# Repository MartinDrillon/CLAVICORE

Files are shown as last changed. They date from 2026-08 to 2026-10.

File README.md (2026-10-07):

# Clavicore 
## Le projet
> Piloter un clavecin à distance grâce à un clavier ergonomique

## L’instrument
La base est une copie d’une épinette italienne de 1601, vendue dans les années 70 en kit par Heugel et montée par un amateur. L’instrument a été révisé (changement des cordes, réharmonisation à la plume, rebouchage d’une fente sur la table d’harmonie). 

Le système électronique sera intégré au corps de l’instrument.

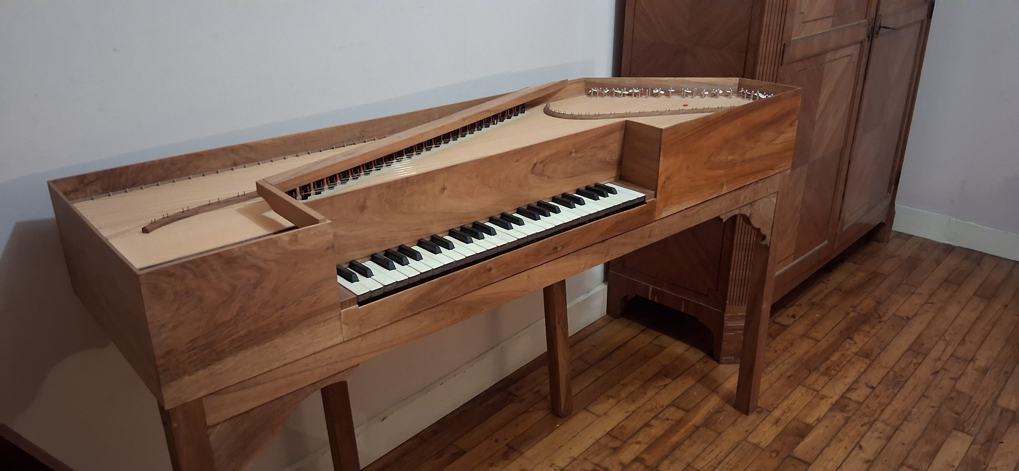
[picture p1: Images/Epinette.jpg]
Épinette


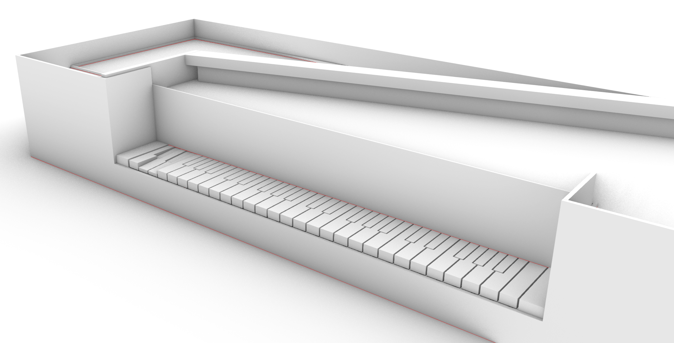
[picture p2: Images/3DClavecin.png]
3D Clavecin


## L’automatisation

## Moitié « Moteur »
*PCB en cours de fabrication*

La carte de contrôle est basée sur un RP2354B avec un DRV8874 par solénoïde pour un contrôle bidirectionnel. Cinq cartes permettent de gérer les 49 touches du clavier. Les cartes communiquent en CAN.

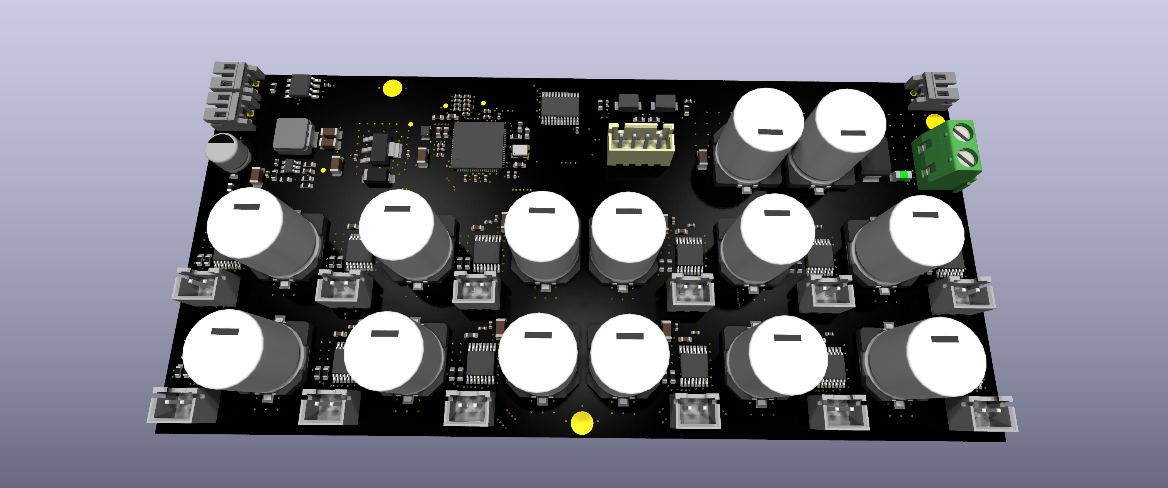
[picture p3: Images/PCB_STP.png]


### Moitié « Clavier »
*PCB en cours de fabrication*

Simple matrice de touches gérée par un Pico 2. Les événements « touches pressées » sont communiqués en CAN avec la partie « moteur » du système. Ils pourront également être transmis en MIDI à un ordinateur.

Ce projet utilisera une base de clavier ergonomique (https://github.com/MartinDrillon/IteMX3-) adaptée pour recevoir une disposition de type « Wiki-Haydn ». Une présentation plus détaillée du clavier est à venir. 

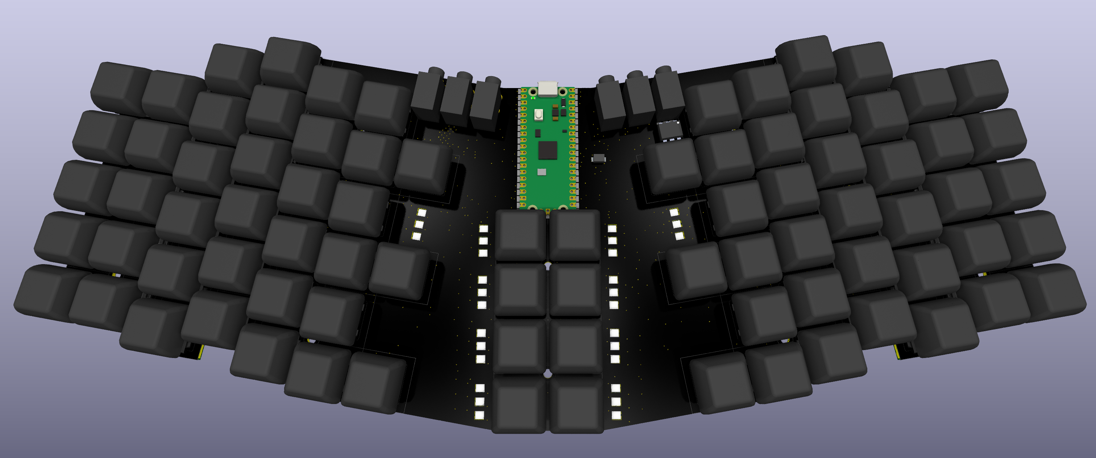
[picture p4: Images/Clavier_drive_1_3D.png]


## Les solénoïdes
Les solénoïdes sont les éléments centraux du montage. Ils doivent être réalisés sur mesure. Ceux disponibles sur le marché sont :
- Trop bruyants
- Trop encombrants
- Trop puissants ou trop faibles
- Trop chers (~5 € pièce pour la référence la plus adaptée)

### Le cahier des charges
- Bobine de 28 mm x 15 mm Ø max, intégrée au corps du clavecin, pour être invisible et conserver la possibilité de jouer normalement.   
- Noyau constitué d’un aimant néodyme de 13 mm x 6 mm Ø N48 fixé sous la touche.
- Alimentation en 24 volts, courant de 2 à 3 ampères
    - Au-delà, la chauffe de la bobine et la puissance nécessaire à un accord deviennent trop importantes
    - En deçà, la force n’est pas suffisante ou le nombre de spires devient trop élevé
- Fil d’un diamètre de 0,3 à 0,4 mm. 
    - Au-delà, la quantité de cuivre par bobine devient trop importante (coût, encombrement, bobinage complexe).
    - En deçà, la force est trop faible ou la chauffe est trop élevée. 

### Le prototype

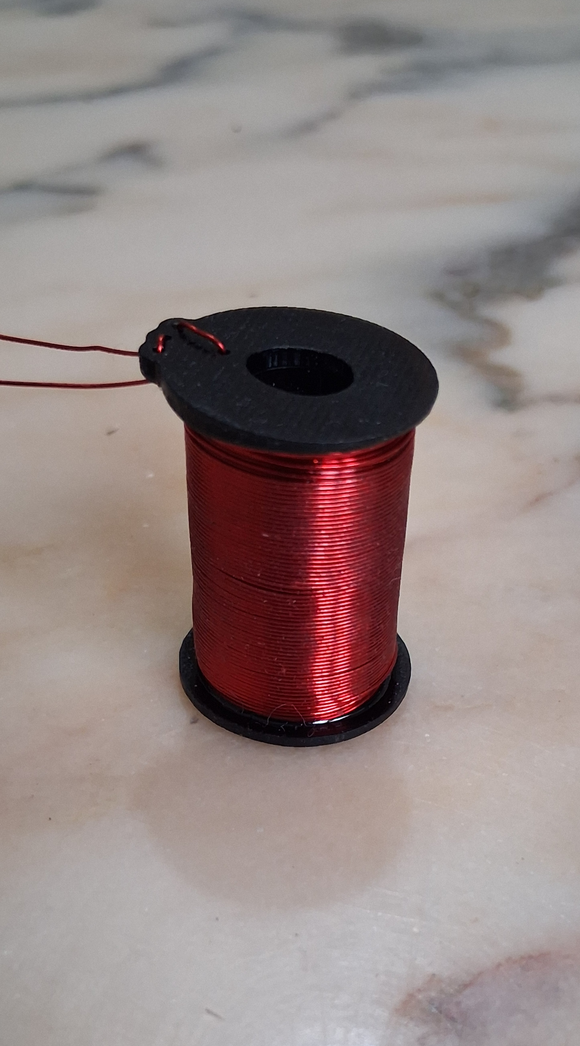
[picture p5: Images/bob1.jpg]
bobine de côté

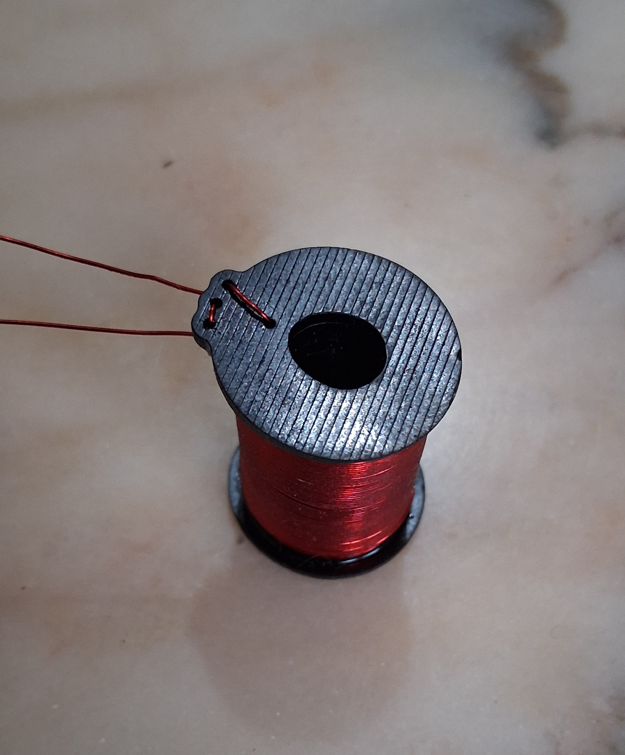
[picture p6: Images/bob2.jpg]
bobine plan


Le mandrin est imprimé en 3D avec une résine industrielle résistante à de hautes températures. Sa section est ovoïde pour permettre le mouvement de l’aimant (qui n’est pas parfaitement vertical, la touche s’enfonçant avec un angle) tout en minimisant l’écart avec les spires. La paroi intérieure ne fait que 0,8mm d’épaisseur. Ce prototype tire environ 2,9 ampères pour 14 couches et un fil de 0,35mm. 

La force max estimée est de 3N, soit environ le double de ce qui est nécessaire au pincement d’une corde. Cette marge devra permettre de garantir la réactivité du système et de compenser la perte de puissance causée par l’échauffement. La force exacte appliquée sera de toute façon controllé en PWM (par exemple 100% pour le pincement, puis très limité pour le maintien de la corde). Ces éléments devront être validés avec un premier prototype fonctionnel.

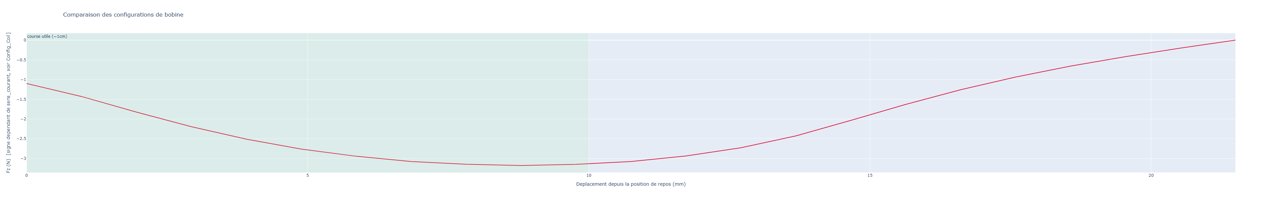
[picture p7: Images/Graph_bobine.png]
Évaluation de la force


## L’état d’avancement 
- [X] Génération d’un script Magpylib pour réaliser un premier dimensionnement des solénoïdes 
- [X] Modélisation 3D de l’instrument
- [X] Conception et impression 3D du corps de la bobine intégré sous les touches
- [X] Premier test concluant avec un fil de 0,4 mm - 2 ampères - 24 volts
- [X] Conception des cartes de pilotage pour l’ensemble du clavecin *pcb en cours de fabrication*
- [X] Conception du clavier ergonomique *pcb en cours de fabrication*
- [ ] Programmation de l’ensemble *en cours*
- [ ] Réalisation artisanale de 50 bobines homogènes et installation du système ! 

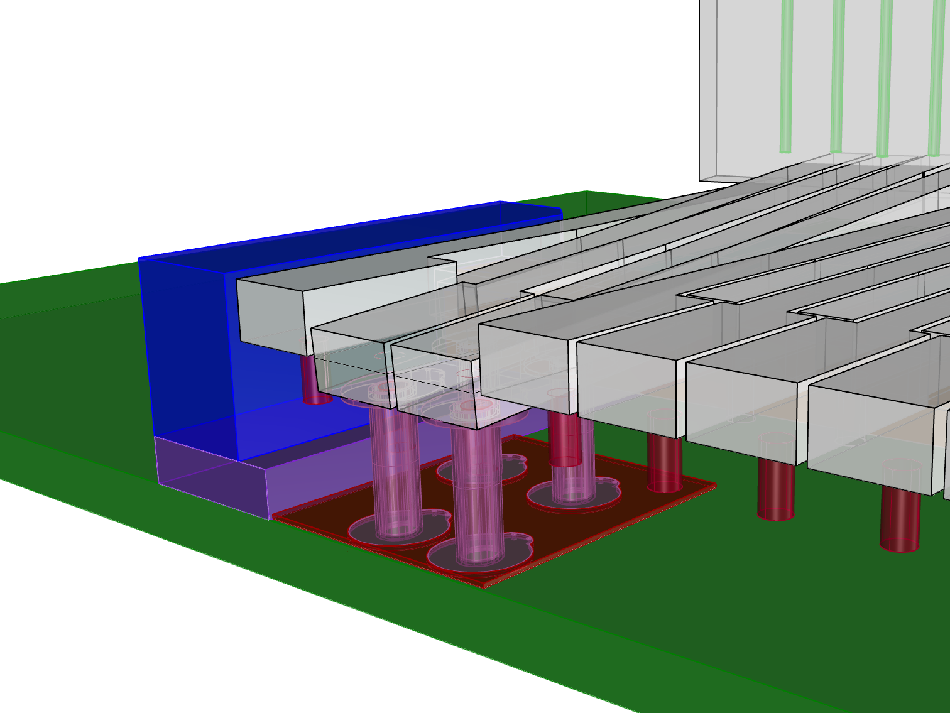
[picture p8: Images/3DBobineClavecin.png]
3D Bobine Clavecin


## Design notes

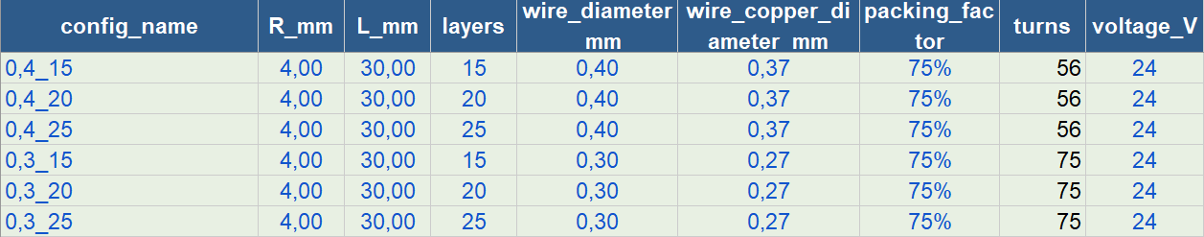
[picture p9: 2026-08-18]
Images/CaracteristiqueBobine.png

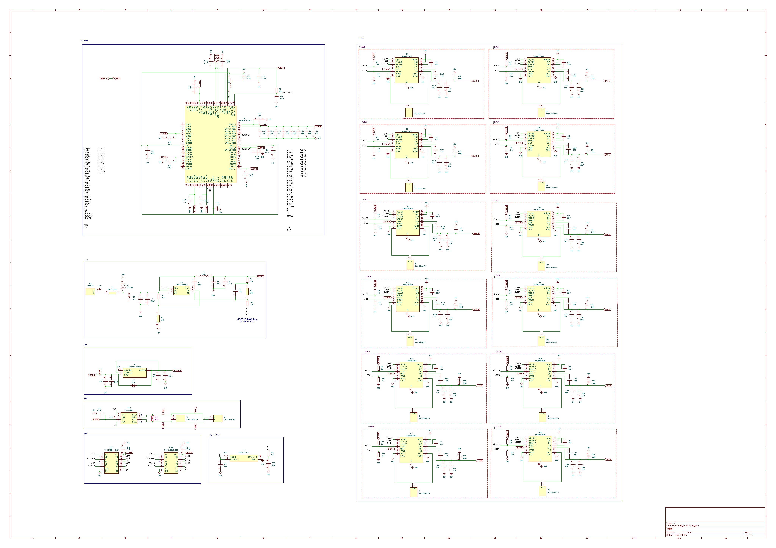
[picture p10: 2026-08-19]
Images/Schéma_moteur.jpg

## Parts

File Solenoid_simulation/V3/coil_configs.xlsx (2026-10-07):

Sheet: Config_Coil
Configurations de bobines — comparaison / dimensionnement
Une ligne = une configuration de bobine. L'aimant N'EST PLUS fixe dans le code : chaque ligne pointe vers une definition d'aimant reutilisable via 'magnet_config' (voir l'onglet Config_Magnet — 'S-06-13-N48' fourni en exemple). turns (couche 0) CALCULE = INT(L_mm/wire_diameter_mm*packing_factor) (texte noir = ne pas modifier). Bobinage IMBRIQUE (orthocyclique) : -1 tour/couche, rayon +diametre*racine(3)/2 par couche. Pour ajouter des tours, joue sur 'layers'. wire_diameter_mm = diametre TOTAL du fil (cuivre + email). wire_copper_diameter_mm = diametre du CUIVRE NU, CALCULE AUTOMATIQUEMENT (texte noir) = wire_diameter_mm - 0.03mm (epaisseur d'email typique) — tape une valeur directement dans la cellule pour ecraser ce calcul si tu as mesure ton fil au pied a coulisse, ou si resistance_measured_ohm (onglet Mesures) indique un diametre effectif different. sens_courant = 'Attire' ou 'Repousse' (liste deroulante) : inverse le sens du courant dans la bobine, donc le sens de la force sur l'aimant (l'orientation de l'aimant lui-meme, definie dans Config_Magnet, reste inchangee). voltage_V = tension d'alim, le courant en resulte (loi d'Ohm). empty_bobbin_weight_g = poids support vide (guide de pesee). quantity = nombre de bobines identiques (cuivre total).
config_name | R_mm | L_mm | layers | wire_diameter_mm | wire_copper_diameter_mm | packing_factor | turns | voltage_V | sens_courant | magnet_config | empty_bobbin_weight_g | quantity
0,35_14 | 4.00 | 28.00 | 14 | 0.35 |  | 90% |  | 24 | Attire | S-06-13-N48 | 1.70 | 50
 |  |  |  |  |  | 80%

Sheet: Config_Magnet
Configurations d'aimants — reutilisables, referencees depuis Config_Coil
Une ligne = un aimant reutilisable, reference depuis Config_Coil via 'magnet_config' (plusieurs bobines peuvent partager le meme aimant). shape = 'cylindre' ou 'carre' (liste deroulante) ; pour 'cylindre', dim1_mm = diametre et dim2_mm est ignore ; pour 'carre' (rectangulaire), dim1_mm et dim2_mm sont les deux cotes de la section. height_mm = epaisseur selon l'axe d'aimantation (les deux formes). grade = grade neodyme standard (liste deroulante, table de reference a droite) -> Br_T = milieu de plage du grade choisi, calcule automatiquement (texte noir). Renseigne Br_override_T (bleu) si tu as la valeur Br exacte de la fiche technique : elle remplace alors le calcul automatique. Position de depart (x0_mm, y0_mm, z0_mm) = position du CENTRE de l'aimant, en mm, avec le CENTRE DE LA BOBINE a l'origine (0,0,0). La bobine (longueur L_mm, onglet Config_Coil) s'etend de -L/2 a +L/2 selon Z. Exemple : aimant pose a fleur du sommet de la bobine (gap=0) -> z0_mm = L/2 + height_mm/2. x0/y0 permettent de simuler un aimant decale lateralement (hors axe).
 |  |  |  |  |  |  |  |  |  |  | Table de reference (grades neodyme standard)
magnet_config | shape | grade | Br_override_T | Br_T | dim1_mm | dim2_mm | height_mm | x0_mm | y0_mm | z0_mm | Grade | Br_min_T | Br_max_T | Br_mid_T
S-06-13-N48 | cylindre | N48 |  |  | 6.00 |  | 13.00 | 0.00 | 0.00 | 21.50 | N35 | 1.170 | 1.220
 |  |  |  |  |  |  |  |  |  |  | N38 | 1.220 | 1.250
 |  |  |  |  |  |  |  |  |  |  | N40 | 1.250 | 1.280
 |  |  |  |  |  |  |  |  |  |  | N42 | 1.280 | 1.320
 |  |  |  |  |  |  |  |  |  |  | N45 | 1.320 | 1.380
 |  |  |  |  |  |  |  |  |  |  | N48 | 1.380 | 1.420
 |  |  |  |  |  |  |  |  |  |  | N50 | 1.400 | 1.450
 |  |  |  |  |  |  |  |  |  |  | N52 | 1.430 | 1.480
 |  |  |  |  |  |  |  |  |  |  | N55 | 1.470 | 1.530
 |  |  |  |  |  |  |  |  |  |  | Source : magmamagnets.com — tableau des caracteristiques
 |  |  |  |  |  |  |  |  |  |  | magnetiques (grades N35-N55). Br_mid_T = milieu de plage.

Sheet: Bobinage_Fabrication
Bobinage — poids, longueur de fil et guide de fabrication
Densite Cu (g/cm3): | 8.92 | Cuivre étamé
Guide de realisation : dimensions, longueur de fil a couper et poids de cuivre pour chaque configuration (depuis Config_Coil). turns_total = somme des tours sur toutes les couches imbriquees. wire_length_m = longueur totale de fil a bobiner. copper_weight_target_g = poids de cuivre pour UNE bobine ; copper_weight_total_qty_g = pour 'quantity' bobines identiques. total_weight_target_g = poids d'une bobine finie (cuivre + support vide) ; total_weight_all_coils_g = poids total du lot complet. lateral_surface_m2 = surface laterale du bobinage (utilisee par l'onglet Electrique pour estimer la convection thermique).
config_name | turns_total | wire_length_m | wire_section_mm2 | outer_diameter_mm | copper_weight_target_g | copper_weight_total_qty_g | total_weight_target_g | lateral_surface_m2 | empty_bobbin_weight_g | quantity | total_weight_all_coils_g

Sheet: Electrique
Caracteristiques electriques et de chauffe (depuis Config_Coil / Bobinage_Fabrication)
Resistivite Cu (Ohm.m): | 1.68e-08 | Temp. ambiante (C): | 25 | h convection (W/m2K): | 10 | Temp. max aimant (C): | 80 | Densite max continue (A/mm2): | 4.0 | Position de maintien (mm): | 10.0 | Duty cycle PWM cible (%): | 3.0% | Constante estim. (N/A.tour): | 0.001073
IMPULSION (orange) = pleine tension sans PWM, bref -> echauffement volontairement extreme, normal. MAINTIEN (vert) = PWM continu -> c'est LUI qui doit rester 'OK'. duty_cycle_hold (bleu) = pourcentage de temps ON du PWM que TU choisis ; par defaut il reprend 'Duty cycle PWM cible' ci-dessus mais peut etre modifie ligne par ligne. force_hold_N / force_hold_g = force de maintien RESULTANTE a ce duty cycle (calculee, ce n'est plus une cible qu'on vise). force_estimate_rapide_N = estimation rapide (F proportionnel aux ampere-tours, PAS ampere-tours^2 : l'aimant est un dipole permanent, pas un noyau qui sature) calibree sur la geometrie ET l'aimant par defaut (R=4mm/L=30mm, S-06-13-N48) -- fiable pres de cette config, ecart possible si la bobine OU l'aimant s'eloigne beaucoup de cette reference. force_dispo_maintien_N (violet) = vraie valeur simulee (magpylib), injectee par batch_compare.py. force_utilisee_N prend la valeur simulee si disponible sinon l'estimation rapide (source_force l'indique).
 | IMPULSION (plein voltage, bref) |  |  |  |  |  | MAINTIEN (PWM, soutenu)
config_name | resistance_ohm | voltage_V | current_full_A | current_density_full_A_mm2 | power_full_W | delta_T_full_C | force_estimate_rapide_N | force_dispo_maintien_N | force_utilisee_N | source_force | duty_cycle_hold | force_hold_N | force_hold_g | current_hold_A | current_density_hold_A_mm2 | power_hold_W | delta_T_hold_C | coil_temp_hold_C | margin_hold_C | status_hold
 |  |  |  |  |  |  |  | 3.1331
 |  |  |  |  |  |  |  | 3.6382
 |  |  |  |  |  |  |  | 3.2336 |  |  | 3.0%
 |  |  |  |  |  |  |  | 2.4188
 |  |  |  |  |  |  |  | 2.1750
 |  |  |  |  |  |  |  | 1.9710

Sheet: Mesures
Mesures — calibration a partir de la resistance mesuree
Mesures reelles faites au multimetre APRES bobinage (optionnel). resistance_measured_ohm (bleu) = ta mesure reelle. Si elle est renseignee, copper_diameter_effective_mm est recalcule a partir de cette resistance (diametre de cuivre qui, avec la longueur de fil theorique, donnerait exactement cette resistance). Compare-le a copper_diameter_theorique_mm (repris de Config_Coil) : si l'ecart est significatif, reporte copper_diameter_effective_mm dans Config_Coil!wire_copper_diameter_mm (en ecrasant la formule automatique) pour recaler tout le modele (Bobinage_Fabrication, Electrique) sur ta fabrication reelle.
config_name | resistance_theorique_ohm | resistance_measured_ohm | ecart_resistance_pct | copper_diameter_theorique_mm | copper_diameter_effective_mm | ecart_diametre_mm

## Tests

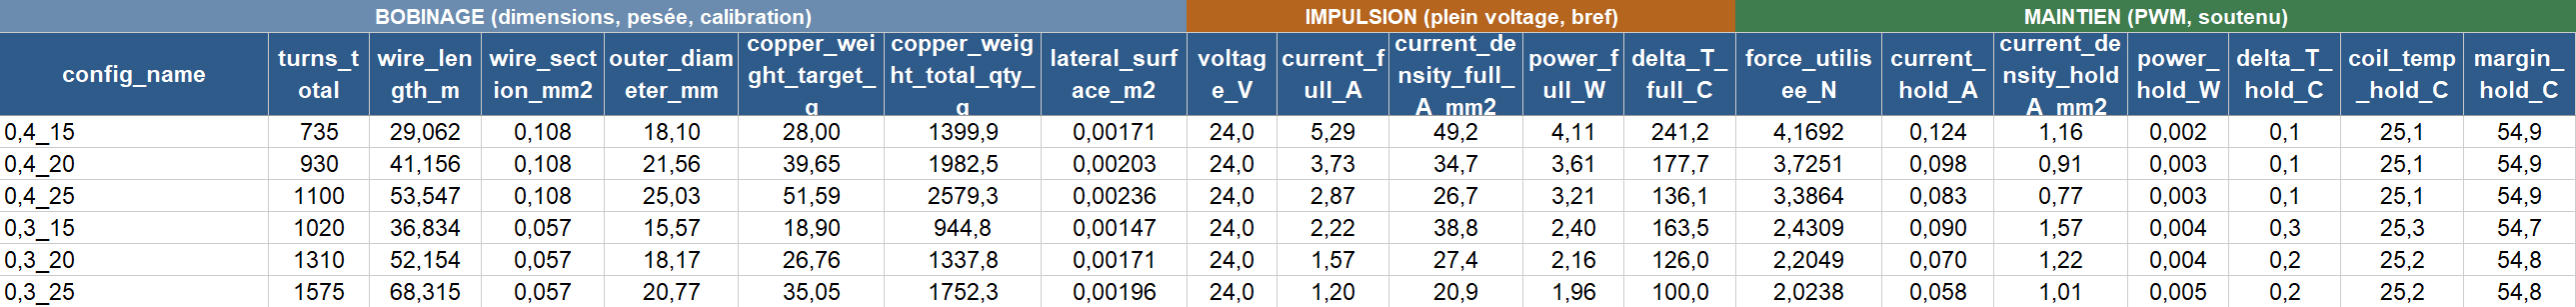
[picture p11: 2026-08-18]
Images/Resultat_test.png

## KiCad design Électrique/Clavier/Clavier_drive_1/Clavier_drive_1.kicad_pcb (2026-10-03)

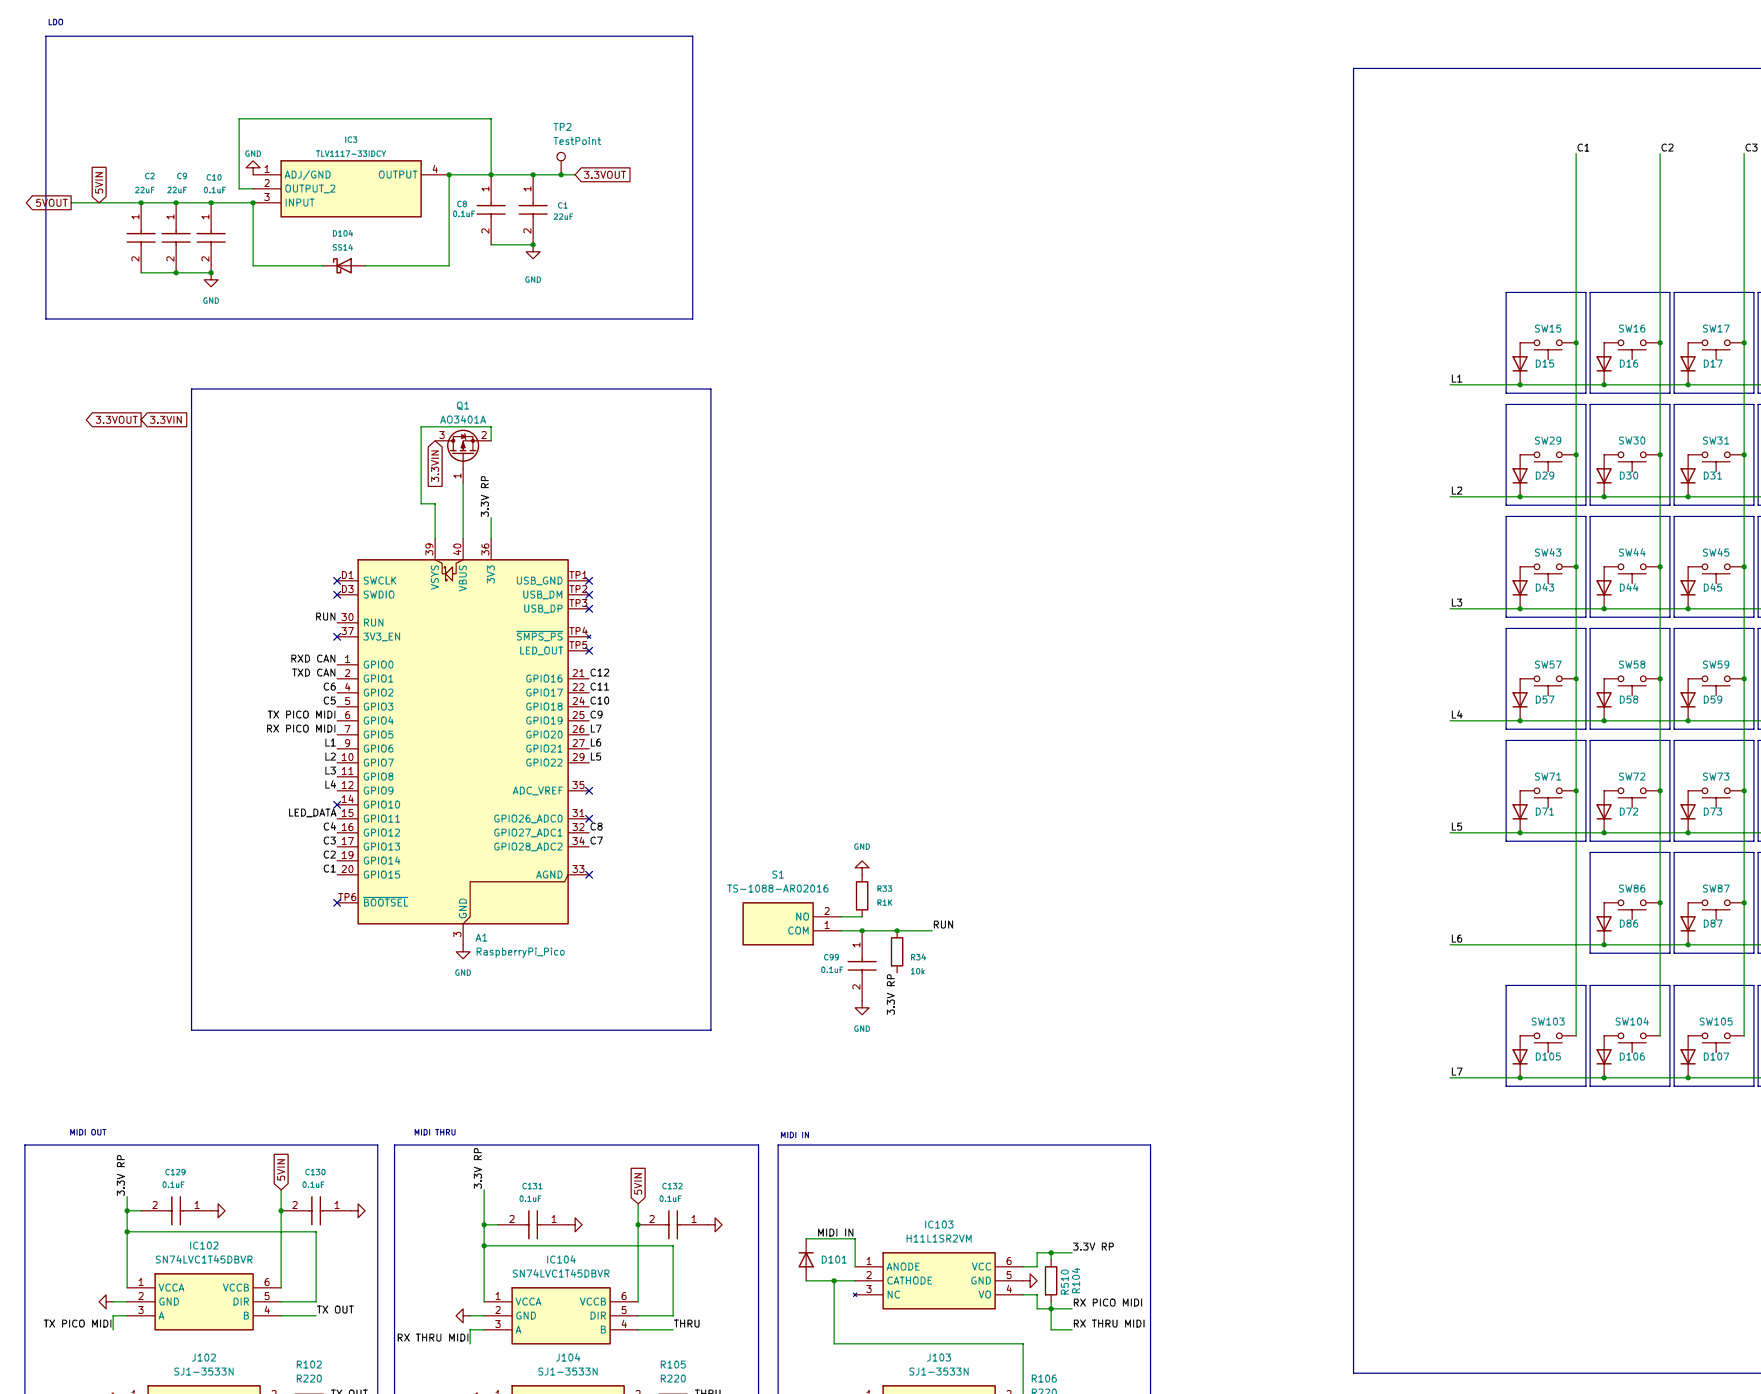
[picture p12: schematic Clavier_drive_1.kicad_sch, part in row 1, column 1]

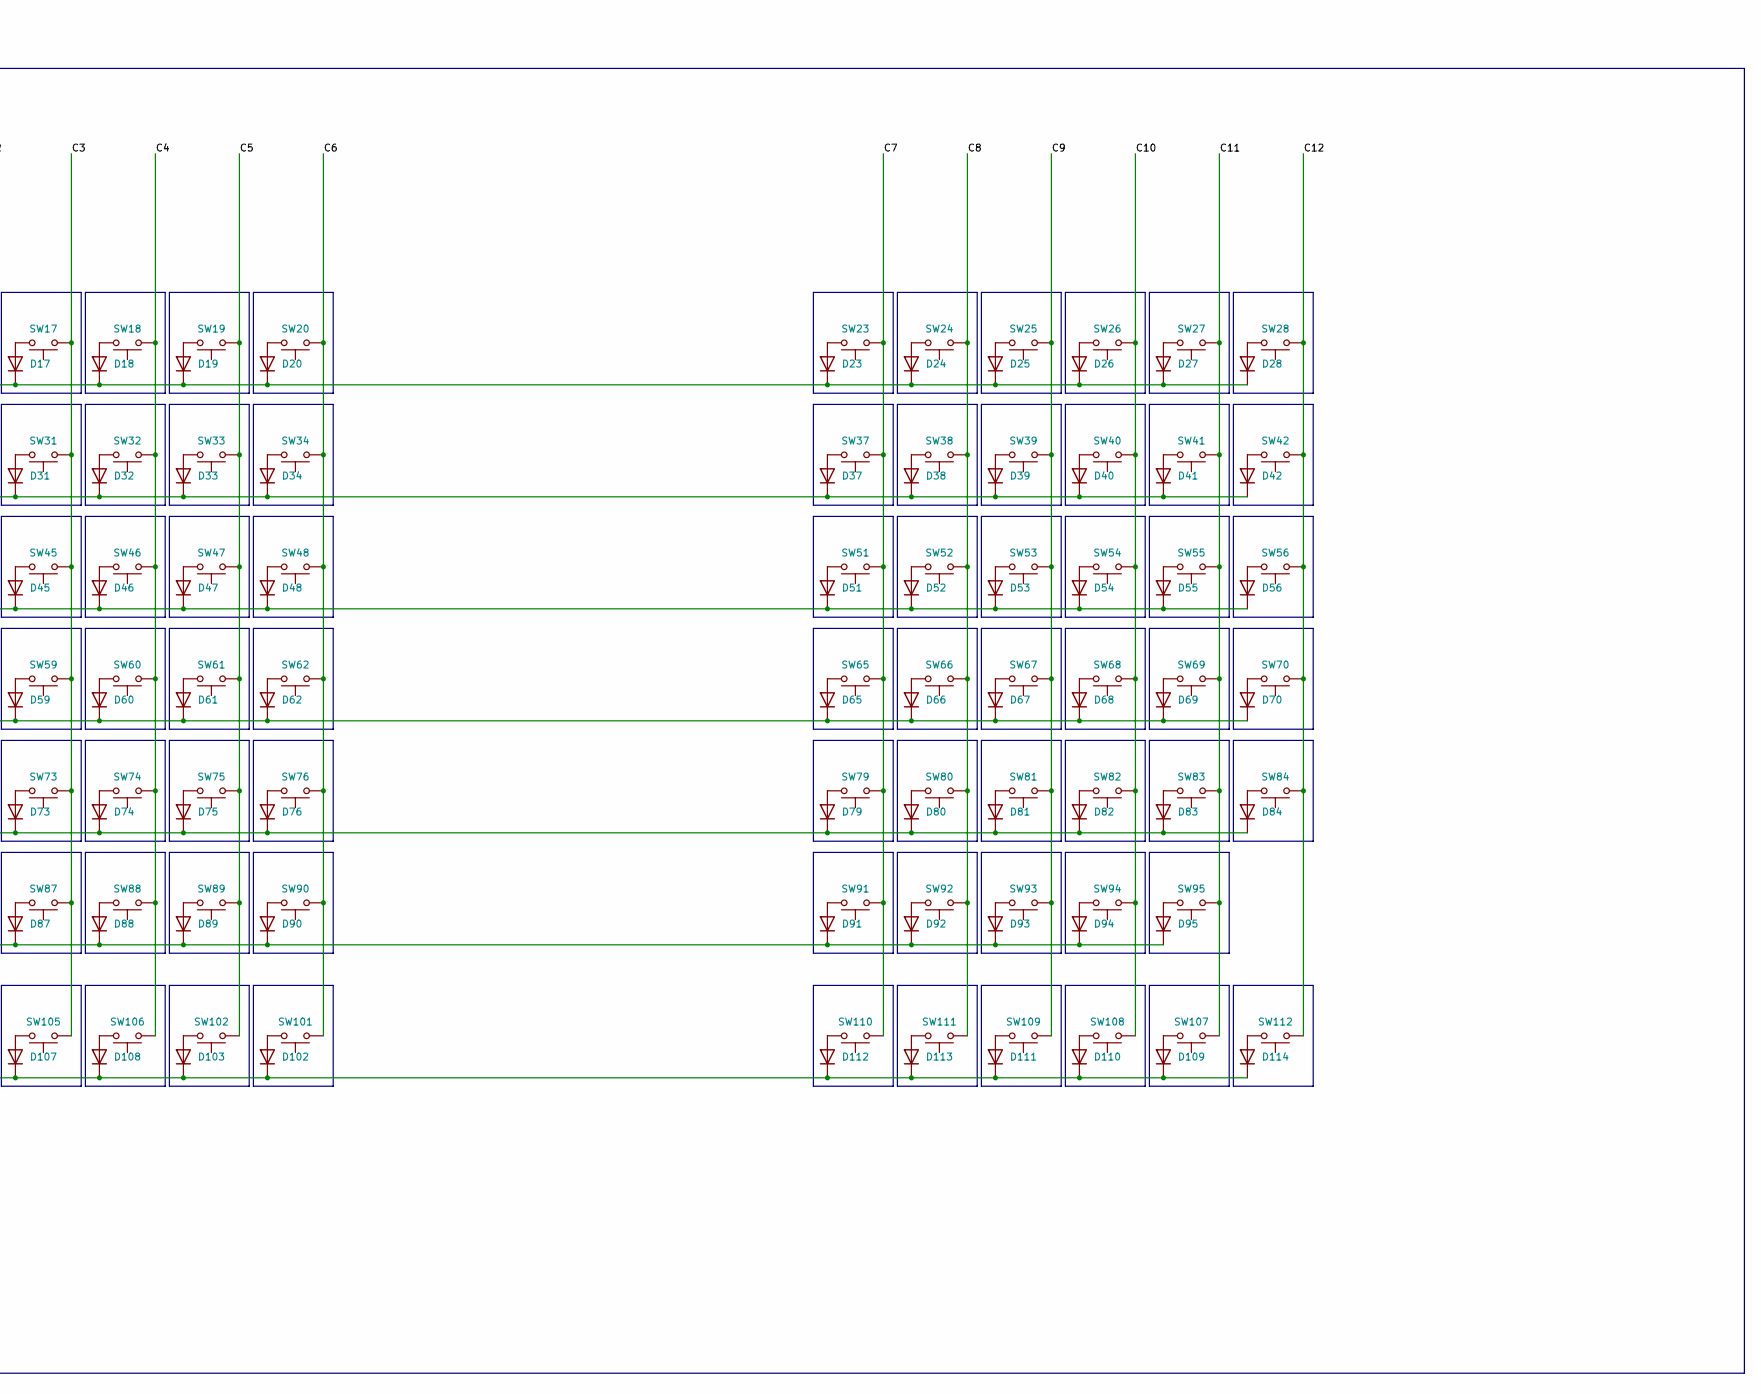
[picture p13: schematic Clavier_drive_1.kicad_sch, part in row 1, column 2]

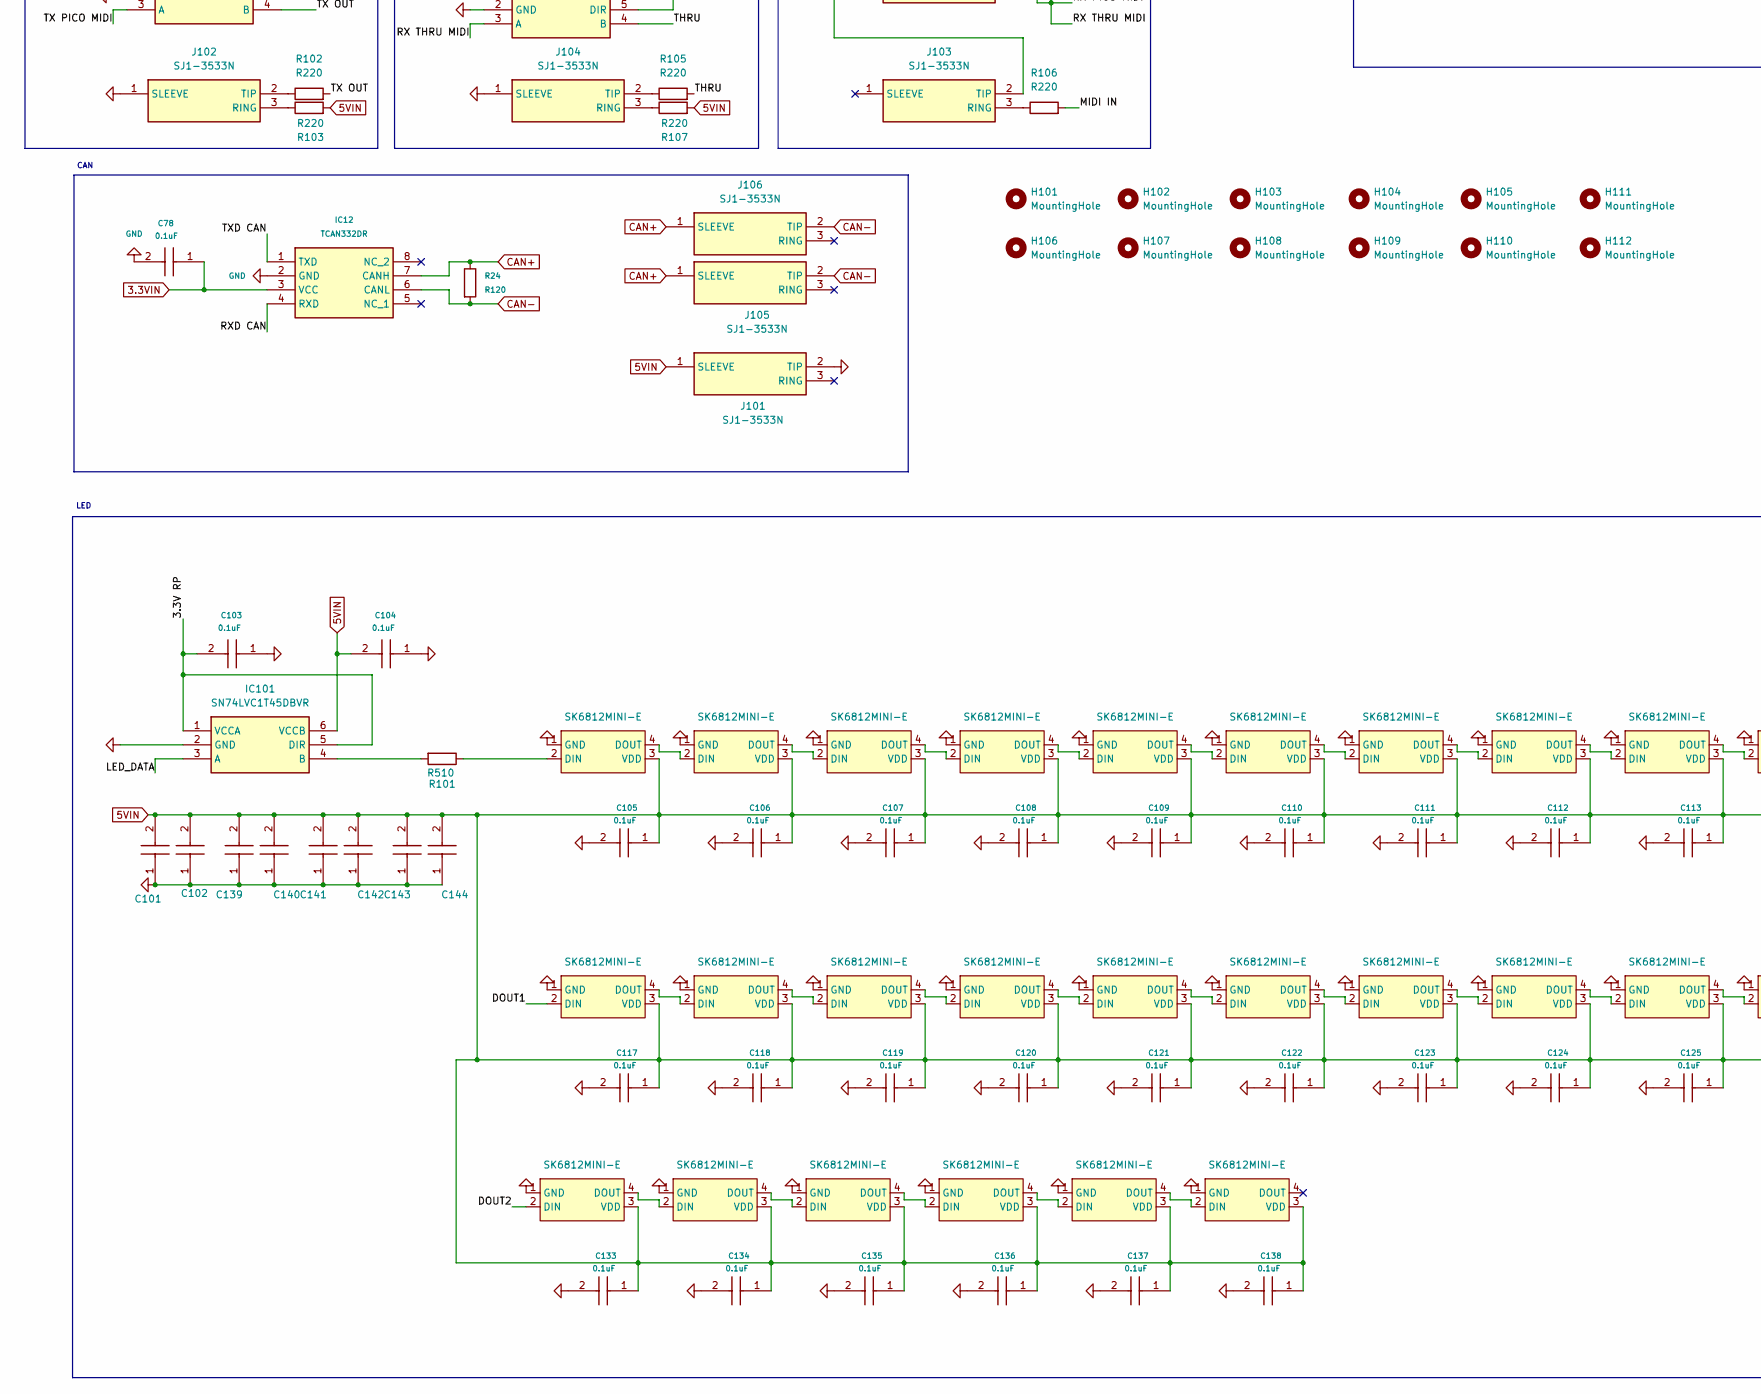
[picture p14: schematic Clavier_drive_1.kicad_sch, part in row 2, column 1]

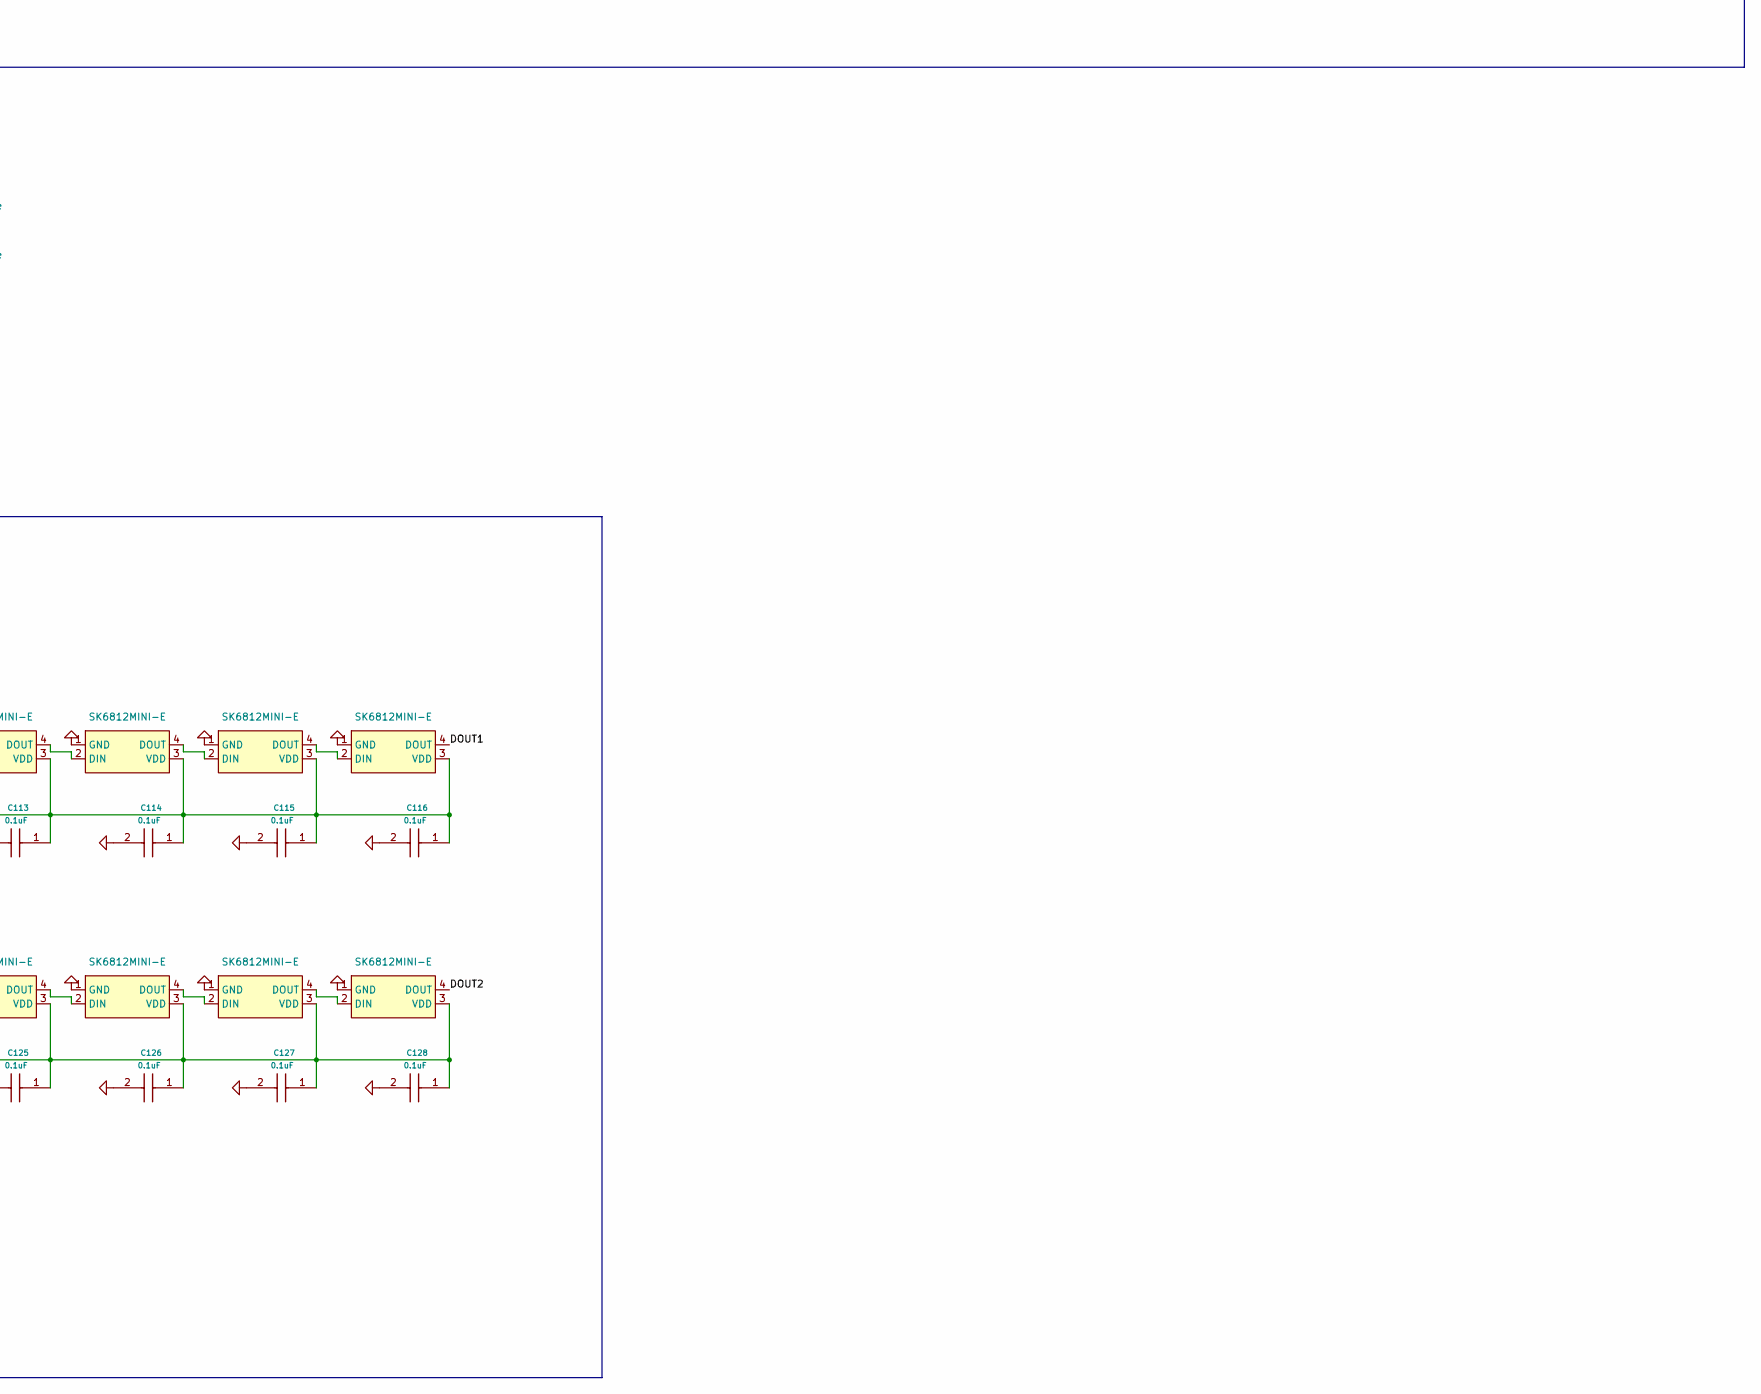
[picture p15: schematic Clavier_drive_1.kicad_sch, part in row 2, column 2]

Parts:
A1: RaspberryPi_Pico; RaspberryPi_Pico_SMD
C1, C2, C9: 22uF; C_1206_3216Metric; Mouser Part Number 187-CL31A226KAHNNNE
C8, C10, C78, C99, C103, C104, C105, C106, C107, C108, C109, C110, C111, C112, C113, C114, C115, C116, C117, C118, C119, C120, C121, C122, C123, C124, C125, C126, C127, C128, C129, C130, C131, C132, C133, C134, C135, C136, C137, C138: 0.1uF; C_0402_1005Metric; Mouser Part Number 603-CC603KRX7R9BB104
C101, C102, C139, C140, C141, C142, C143, C144: CL31A476MPHNNNE; CAPC3216X180N; Mouser Part Number 187-CL31A476MPHNNNE
D15, D16, D17, D18, D19, D20, D23, D24, D25, D26, D27, D28, D29, D30, D31, D32, D33, D34, D37, D38, D39, D40, D41, D42, D43, D44, D45, D46, D47, D48, D51, D52, D53, D54, D55, D56, D57, D58, D59, D60, D61, D62, D65, D66, D67, D68, D69, D70, D71, D72, D73, D74, D75, D76, D79, D80, D81, D82, D83, D84, D86, D87, D88, D89, D90, D91, D92, D93, D94, D95, D101, D102, D103, D105, D106, D107, D108, D109, D110, D111, D112, D113, D114: 1N4148W; D_SOD-123
D104: SS14; D_SMA
H101, H102, H103, H104, H105, H106, H107, H108, H109, H110, H111, H112: MountingHole; MountingHole_3.2mm_M3_DIN965
IC3: TLV1117-33IDCY; SOT230P700X180-4N; Mouser Part Number 595-TLV1117-33IDCY
IC12: TCAN332DR; SOIC127P600X175-8N; Mouser Part Number 595-TCAN332DR
IC101, IC102, IC104: SN74LVC1T45DBVR; SOT95P280X145-6N; Mouser Part Number 595-SN74LVC1T45DBVR
IC103: H11L1SR2VM; Mouser Part Number 512-H11L1SR2VM
J101, J102, J103, J104, J105, J106: SJ1-3533N; SJ13533N; Mouser Part Number 490-SJ1-3533N
LED101, LED102, LED103, LED104, LED105, LED106, LED107, LED108, LED109, LED110, LED111, LED112, LED113, LED114, LED115, LED116, LED117, LED118, LED119, LED120, LED121, LED122, LED123, LED124, LED125, LED126, LED127, LED128, LED129, LED130: SK6812MINI-E; LED-SMD_4P-L3.2-W2.8-LS5.9_SK6812MINI-E; MPN SK6812MINI-E; LCSC Part C5149201
Q1: AO3401A; SOT-23
R24: R120; R_0603_1608Metric
R33: R1K; R_0603_1608Metric
R34: 10k; R_0603_1608Metric
R101, R104: R510; R_0603_1608Metric
R102, R103, R105, R106, R107: R220; R_0603_1608Metric
S1: TS-1088-AR02016; TS1088AR02016; Manufacturer_Part_Number TS-1088-AR02016
SW15, SW16, SW17, SW18, SW19, SW20, SW23, SW24, SW25, SW26, SW27, SW28, SW29, SW30, SW31, SW32, SW33, SW34, SW37, SW38, SW39, SW40, SW41, SW42, SW43, SW44, SW45, SW46, SW47, SW48, SW51, SW52, SW53, SW54, SW55, SW56, SW57, SW58, SW59, SW60, SW61, SW62, SW65, SW66, SW67, SW68, SW69, SW70, SW71, SW72, SW73, SW74, SW75, SW76, SW79, SW80, SW81, SW82, SW83, SW84, SW86, SW87, SW88, SW89, SW90, SW91, SW92, SW93, SW94, SW95, SW101, SW102, SW103, SW104, SW105, SW106, SW107, SW108, SW109, SW110, SW111, SW112: Switch; SW_MX_HS_CPG151101S11_1u
TP2: TestPoint; TestPoint_Pad_D1.0mm_Silkless

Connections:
3.3VIN: C1.1, C8.1, C78.1, D104.2 (A), IC3.2 (OUTPUT_2), IC3.4 (OUTPUT), IC12.3 (VCC), Q1.3 (D), TP2.1 (1_1)
5VIN: C2.1, C9.1, C10.1, C101.2, C102.2, C104.2, C105.1, C106.1, C107.1, C108.1, C109.1, C110.1, C111.1, C112.1, C113.1, C114.1, C115.1, C116.1, C117.1, C118.1, C119.1, C120.1, C121.1, C122.1, C123.1, C124.1, C125.1, C126.1, C127.1, C128.1, C130.2, C132.2, C133.1, C134.1, C135.1, C136.1, C137.1, C138.1, C139.2, C140.2, C141.2, C142.2, C143.2, C144.2, D104.1 (K), IC3.3 (INPUT), IC101.6 (VCCB), IC102.6 (VCCB), IC104.6 (VCCB), J101.1 (SLEEVE), LED101.3 (VDD), LED102.3 (VDD), LED103.3 (VDD), LED104.3 (VDD), LED105.3 (VDD), LED106.3 (VDD), LED107.3 (VDD), LED108.3 (VDD), LED109.3 (VDD), LED110.3 (VDD), LED111.3 (VDD), LED112.3 (VDD), LED113.3 (VDD), LED114.3 (VDD), LED115.3 (VDD), LED116.3 (VDD), LED117.3 (VDD), LED118.3 (VDD), LED119.3 (VDD), LED120.3 (VDD), LED121.3 (VDD), LED122.3 (VDD), LED123.3 (VDD), LED124.3 (VDD), LED125.3 (VDD), LED126.3 (VDD), LED127.3 (VDD), LED128.3 (VDD), LED129.3 (VDD), LED130.3 (VDD), R103.2, R107.2
/3.3V RP: A1.36 (3V3), C103.2, C129.2, C131.2, IC101.1 (VCCA), IC101.5 (DIR), IC102.1 (VCCA), IC102.5 (DIR), IC103.6 (VCC), IC104.1 (VCCA), IC104.5 (DIR), R34.2, R104.1
/C1: A1.20 (GPIO15), SW15.1, SW29.1, SW43.1, SW57.1, SW71.1, SW103.1
/C2: A1.19 (GPIO14), SW16.1, SW30.1, SW44.1, SW58.1, SW72.1, SW86.1, SW104.1
/C3: A1.17 (GPIO13), SW17.1, SW31.1, SW45.1, SW59.1, SW73.1, SW87.1, SW105.1
/C4: A1.16 (GPIO12), SW18.1, SW32.1, SW46.1, SW60.1, SW74.1, SW88.1, SW106.1
/C5: A1.5 (GPIO3), SW19.1, SW33.1, SW47.1, SW61.1, SW75.1, SW89.1, SW102.1
/C6: A1.4 (GPIO2), SW20.1, SW34.1, SW48.1, SW62.1, SW76.1, SW90.1, SW101.1
/C7: A1.34 (GPIO28_ADC2), SW23.1, SW37.1, SW51.1, SW65.1, SW79.1, SW91.1, SW110.1
/C8: A1.32 (GPIO27_ADC1), SW24.1, SW38.1, SW52.1, SW66.1, SW80.1, SW92.1, SW111.1
/C9: A1.25 (GPIO19), SW25.1, SW39.1, SW53.1, SW67.1, SW81.1, SW93.1, SW109.1
/C10: A1.24 (GPIO18), SW26.1, SW40.1, SW54.1, SW68.1, SW82.1, SW94.1, SW108.1
/C11: A1.22 (GPIO17), SW27.1, SW41.1, SW55.1, SW69.1, SW83.1, SW95.1, SW107.1
/C12: A1.21 (GPIO16), SW28.1, SW42.1, SW56.1, SW70.1, SW84.1, SW112.1
/DOUT1: LED112.4 (DOUT), LED113.2 (DIN)
/DOUT2: LED124.4 (DOUT), LED125.2 (DIN)
/L1: A1.9 (GPIO6), D15.1 (K), D16.1 (K), D17.1 (K), D18.1 (K), D19.1 (K), D20.1 (K), D23.1 (K), D24.1 (K), D25.1 (K), D26.1 (K), D27.1 (K), D28.1 (K)
/L2: A1.10 (GPIO7), D29.1 (K), D30.1 (K), D31.1 (K), D32.1 (K), D33.1 (K), D34.1 (K), D37.1 (K), D38.1 (K), D39.1 (K), D40.1 (K), D41.1 (K), D42.1 (K)
/L3: A1.11 (GPIO8), D43.1 (K), D44.1 (K), D45.1 (K), D46.1 (K), D47.1 (K), D48.1 (K), D51.1 (K), D52.1 (K), D53.1 (K), D54.1 (K), D55.1 (K), D56.1 (K)
/L4: A1.12 (GPIO9), D57.1 (K), D58.1 (K), D59.1 (K), D60.1 (K), D61.1 (K), D62.1 (K), D65.1 (K), D66.1 (K), D67.1 (K), D68.1 (K), D69.1 (K), D70.1 (K)
/L5: A1.29 (GPIO22), D71.1 (K), D72.1 (K), D73.1 (K), D74.1 (K), D75.1 (K), D76.1 (K), D79.1 (K), D80.1 (K), D81.1 (K), D82.1 (K), D83.1 (K), D84.1 (K)
/L6: A1.27 (GPIO21), D86.1 (K), D87.1 (K), D88.1 (K), D89.1 (K), D90.1 (K), D91.1 (K), D92.1 (K), D93.1 (K), D94.1 (K), D95.1 (K)
/L7: A1.26 (GPIO20), D102.1 (K), D103.1 (K), D105.1 (K), D106.1 (K), D107.1 (K), D108.1 (K), D109.1 (K), D110.1 (K), D111.1 (K), D112.1 (K), D113.1 (K), D114.1 (K)
/LED_DATA: A1.15 (GPIO11), IC101.3 (A)
/MIDI IN: D101.1 (K), IC103.1 (ANODE), R106.2
/RUN: A1.30 (RUN), C99.1, R34.1, S1.1 (COM)
/RXD CAN: A1.1 (GPIO0), IC12.4 (RXD)
/THRU: IC104.4 (B), R105.2
/TX OUT: IC102.4 (B), R102.2
/TX PICO MIDI: A1.6 (GPIO4), IC102.3 (A)
/TXD CAN: A1.2 (GPIO1), IC12.1 (TXD)
/ RX PICO MIDI: A1.7 (GPIO5), IC103.4 (VO), IC104.3 (A), R104.2
CAN+: IC12.7 (CANH), J105.1 (SLEEVE), J106.1 (SLEEVE), R24.1
CAN-: IC12.6 (CANL), J105.2 (TIP), J106.2 (TIP), R24.2
GND: A1.3 (GND), A1.8 (GND), A1.13 (GND), A1.18 (GND), A1.23 (GND), A1.28 (GND), A1.38 (GND), A1.D2 (GND), C1.2, C2.2, C8.2, C9.2, C10.2, C78.2, C99.2, C101.1, C102.1, C103.1, C104.1, C105.2, C106.2, C107.2, C108.2, C109.2, C110.2, C111.2, C112.2, C113.2, C114.2, C115.2, C116.2, C117.2, C118.2, C119.2, C120.2, C121.2, C122.2, C123.2, C124.2, C125.2, C126.2, C127.2, C128.2, C129.1, C130.1, C131.1, C132.1, C133.2, C134.2, C135.2, C136.2, C137.2, C138.2, C139.1, C140.1, C141.1, C142.1, C143.1, C144.1, IC3.1 (ADJ/GND), IC12.2 (GND), IC101.2 (GND), IC102.2 (GND), IC103.5 (GND), IC104.2 (GND), J101.2 (TIP), J102.1 (SLEEVE), J104.1 (SLEEVE), LED101.1 (GND), LED102.1 (GND), LED103.1 (GND), LED104.1 (GND), LED105.1 (GND), LED106.1 (GND), LED107.1 (GND), LED108.1 (GND), LED109.1 (GND), LED110.1 (GND), LED111.1 (GND), LED112.1 (GND), LED113.1 (GND), LED114.1 (GND), LED115.1 (GND), LED116.1 (GND), LED117.1 (GND), LED118.1 (GND), LED119.1 (GND), LED120.1 (GND), LED121.1 (GND), LED122.1 (GND), LED123.1 (GND), LED124.1 (GND), LED125.1 (GND), LED126.1 (GND), LED127.1 (GND), LED128.1 (GND), LED129.1 (GND), LED130.1 (GND), R33.1
unnamed: A1.40 (VBUS), Q1.1 (G)
unnamed: A1.39 (VSYS), Q1.2 (S)
unnamed: D15.2 (A), SW15.2
unnamed: D16.2 (A), SW16.2
unnamed: D17.2 (A), SW17.2
unnamed: D18.2 (A), SW18.2
unnamed: D19.2 (A), SW19.2
unnamed: D20.2 (A), SW20.2
unnamed: D23.2 (A), SW23.2
unnamed: D24.2 (A), SW24.2
unnamed: D25.2 (A), SW25.2
unnamed: D26.2 (A), SW26.2
unnamed: D27.2 (A), SW27.2
unnamed: D28.2 (A), SW28.2
unnamed: D29.2 (A), SW29.2
unnamed: D30.2 (A), SW30.2
unnamed: D31.2 (A), SW31.2
unnamed: D32.2 (A), SW32.2
unnamed: D33.2 (A), SW33.2
unnamed: D34.2 (A), SW34.2
unnamed: D37.2 (A), SW37.2
unnamed: D38.2 (A), SW38.2
unnamed: D39.2 (A), SW39.2
unnamed: D40.2 (A), SW40.2
unnamed: D41.2 (A), SW41.2
unnamed: D42.2 (A), SW42.2
unnamed: D43.2 (A), SW43.2
unnamed: D44.2 (A), SW44.2
unnamed: D45.2 (A), SW45.2
unnamed: D46.2 (A), SW46.2
unnamed: D47.2 (A), SW47.2
unnamed: D48.2 (A), SW48.2
unnamed: D51.2 (A), SW51.2
unnamed: D52.2 (A), SW52.2
unnamed: D53.2 (A), SW53.2
unnamed: D54.2 (A), SW54.2
unnamed: D55.2 (A), SW55.2
unnamed: D56.2 (A), SW56.2
unnamed: D57.2 (A), SW57.2
unnamed: D58.2 (A), SW58.2
unnamed: D59.2 (A), SW59.2
unnamed: D60.2 (A), SW60.2
unnamed: D61.2 (A), SW61.2
unnamed: D62.2 (A), SW62.2
unnamed: D65.2 (A), SW65.2
unnamed: D66.2 (A), SW66.2
unnamed: D67.2 (A), SW67.2
unnamed: D68.2 (A), SW68.2
unnamed: D69.2 (A), SW69.2
unnamed: D70.2 (A), SW70.2
unnamed: D71.2 (A), SW71.2
unnamed: D72.2 (A), SW72.2
unnamed: D73.2 (A), SW73.2
unnamed: D74.2 (A), SW74.2
unnamed: D75.2 (A), SW75.2
unnamed: D76.2 (A), SW76.2
unnamed: D79.2 (A), SW79.2
unnamed: D80.2 (A), SW80.2
unnamed: D81.2 (A), SW81.2
unnamed: D82.2 (A), SW82.2
unnamed: D83.2 (A), SW83.2
unnamed: D84.2 (A), SW84.2
unnamed: D86.2 (A), SW86.2
unnamed: D87.2 (A), SW87.2
unnamed: D88.2 (A), SW88.2
unnamed: D89.2 (A), SW89.2
unnamed: D90.2 (A), SW90.2
unnamed: D91.2 (A), SW91.2
unnamed: D92.2 (A), SW92.2
unnamed: D93.2 (A), SW93.2
unnamed: D94.2 (A), SW94.2
unnamed: D95.2 (A), SW95.2
unnamed: D101.2 (A), IC103.2 (CATHODE), J103.2 (TIP)
unnamed: D102.2 (A), SW101.2
unnamed: D103.2 (A), SW102.2
unnamed: D105.2 (A), SW103.2
unnamed: D106.2 (A), SW104.2
unnamed: D107.2 (A), SW105.2
unnamed: D108.2 (A), SW106.2
unnamed: D109.2 (A), SW107.2
unnamed: D110.2 (A), SW108.2
unnamed: D111.2 (A), SW109.2
unnamed: D112.2 (A), SW110.2
unnamed: D113.2 (A), SW111.2
unnamed: D114.2 (A), SW112.2
unnamed: IC101.4 (B), R101.2
unnamed: J102.3 (RING), R103.1
unnamed: J102.2 (TIP), R102.1
unnamed: J103.3 (RING), R106.1
unnamed: J104.3 (RING), R107.1
unnamed: J104.2 (TIP), R105.1
unnamed: LED101.2 (DIN), R101.1
unnamed: LED101.4 (DOUT), LED102.2 (DIN)
unnamed: LED102.4 (DOUT), LED103.2 (DIN)
unnamed: LED103.4 (DOUT), LED104.2 (DIN)
unnamed: LED104.4 (DOUT), LED105.2 (DIN)
unnamed: LED105.4 (DOUT), LED106.2 (DIN)
unnamed: LED106.4 (DOUT), LED107.2 (DIN)
unnamed: LED107.4 (DOUT), LED108.2 (DIN)
unnamed: LED108.4 (DOUT), LED109.2 (DIN)
unnamed: LED109.4 (DOUT), LED110.2 (DIN)
unnamed: LED110.4 (DOUT), LED111.2 (DIN)
unnamed: LED111.4 (DOUT), LED112.2 (DIN)
unnamed: LED113.4 (DOUT), LED114.2 (DIN)
unnamed: LED114.4 (DOUT), LED115.2 (DIN)
unnamed: LED115.4 (DOUT), LED116.2 (DIN)
unnamed: LED116.4 (DOUT), LED117.2 (DIN)
unnamed: LED117.4 (DOUT), LED118.2 (DIN)
unnamed: LED118.4 (DOUT), LED119.2 (DIN)
unnamed: LED119.4 (DOUT), LED120.2 (DIN)
unnamed: LED120.4 (DOUT), LED121.2 (DIN)
unnamed: LED121.4 (DOUT), LED122.2 (DIN)
unnamed: LED122.4 (DOUT), LED123.2 (DIN)
unnamed: LED123.4 (DOUT), LED124.2 (DIN)
unnamed: LED125.4 (DOUT), LED126.2 (DIN)
unnamed: LED126.4 (DOUT), LED127.2 (DIN)
unnamed: LED127.4 (DOUT), LED128.2 (DIN)
unnamed: LED128.4 (DOUT), LED129.2 (DIN)
unnamed: LED129.4 (DOUT), LED130.2 (DIN)
unnamed: R33.2, S1.2 (NO)

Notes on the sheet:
MIDI OUT
LED
MIDI IN
CAN
LDO
MIDI THRU

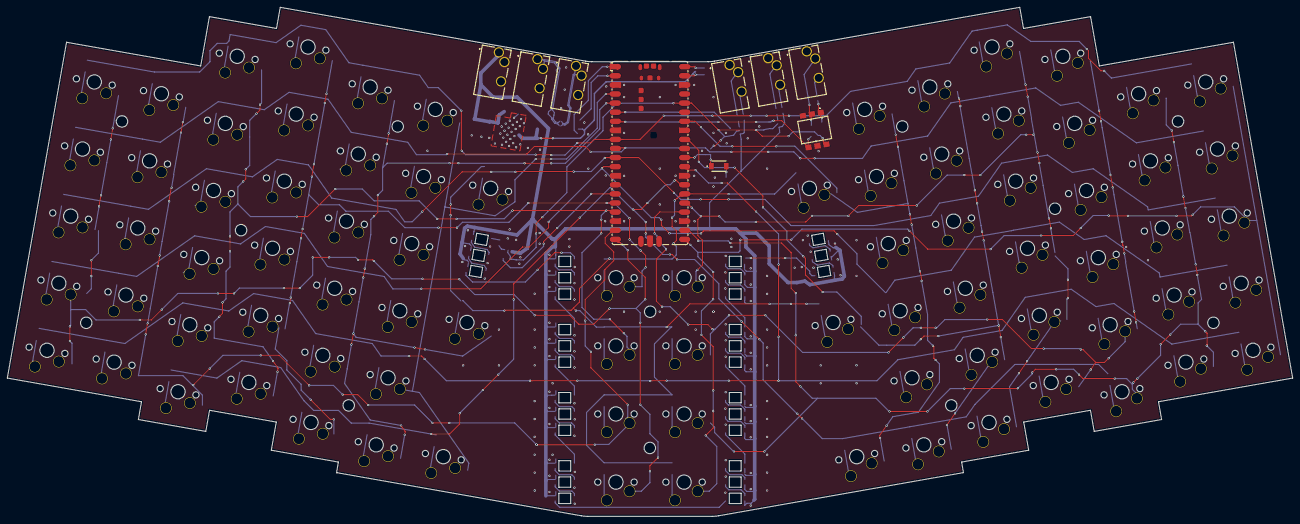
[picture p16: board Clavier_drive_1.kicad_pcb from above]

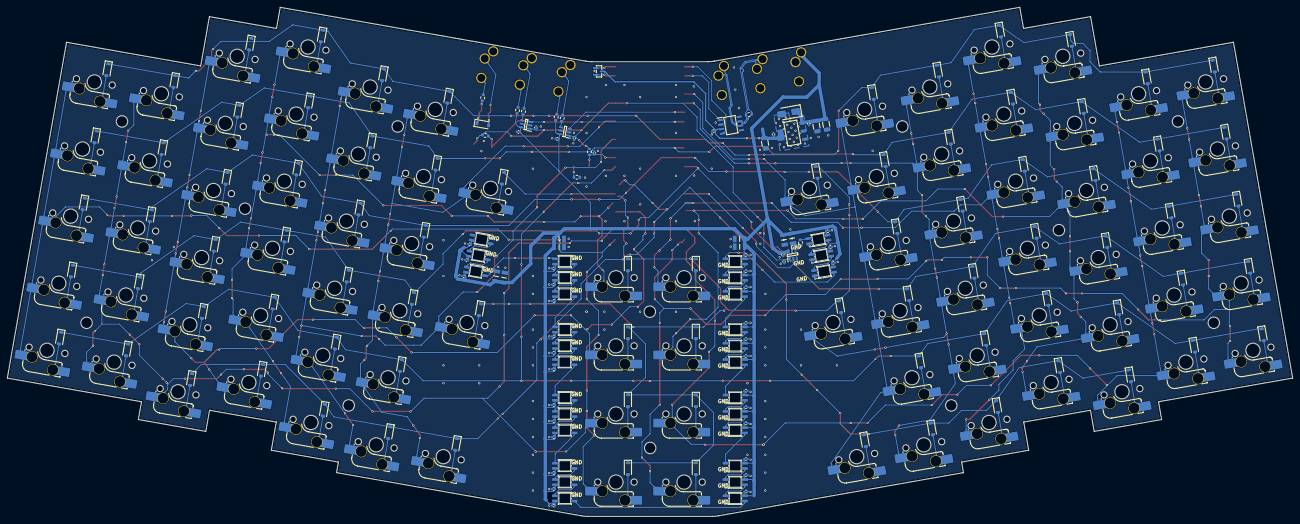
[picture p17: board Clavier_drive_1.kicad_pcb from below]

Board: 2 copper layers, 359.4 x 142.3 mm, 285 parts (264 on the bottom side), 156 nets.

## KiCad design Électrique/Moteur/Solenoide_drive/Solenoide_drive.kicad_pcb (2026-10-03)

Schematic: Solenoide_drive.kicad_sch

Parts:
C1, C4, C5, C9: 22uF; C_1206_3216Metric; Mouser Part Number 187-CL31A226KAHNNNE
C2, C3, C8, C10, C14, C15, C16, C17, C18, C19, C20, C21, C22, C23, C24, C25, C26, C29, C33, C35, C37, C39, C42, C45, C46, C48, C50, C51, C54, C56, C58, C60, C62, C63, C66, C68, C70, C73, C74, C75, C78, C82, C83, C84, C85, C86, C87, C88, C89, C98, C99, C104: 0.1uF; C_0402_1005Metric; Mouser Part Number 603-CC603KRX7R9BB104
C6: 75pF; C_0603_1608Metric; Manufacturer_Part_Number CC0402JRNPO9BN750
C7, C30, C36, C43, C47, C55, C59, C67, C71, C90, C91, C92, C93, C100: 10uF; C_1206_3216Metric; Mouser Part Number 187-CL31A106KBHNNNE
C11, C12, C13, C27: 4.7uF; C_0603_1608Metric
C28, C31, C34, C40, C41, C52, C53, C64, C65, C79, C80, C81: 22nF; C_0603_1608Metric
C32, C38, C44, C49, C57, C61, C69, C72, C94, C95, C96, C97, C101, C102: C680; CAP-SMD_BD12.5-L13.0-W13.0-LS14.4-FD; JLCPCB Part C90272
C76, C77: 15pF; C_0603_1608Metric; Mouser Part Number 187-CL10C150JB8NNNC
C103: EEE-FK1H100P; EEE1AA101SP; Mouser Part Number 667-EEE-FK1H100P
D1: SMCJ26CAHE3_A/H; DIOM7959X262N; Mouser Part Number 576-SMCJ28A
D2: SS14; D_SMA
F1: 0458010.DR; FUSC3216X158N; Mouser Part Number 576-0458010.DR
FB1: BLM18PG121SN1D; BLM18SP221SN1B; Mouser Part Number 81-BLM18PG121SN1D
IC1: SC1510_13_-A4; QFN40P1000X1000X90-81N-D; Manufacturer_Part_Number SC2212
IC2: TPS54302DDCR; SOT95P280X110-6N; Mouser Part Number 595-TPS54302DDCR
IC3: TLV1117-33IDCY; SOT230P700X180-4N; Mouser Part Number 595-TLV1117-33IDCY
IC4, IC5, IC6, IC7, IC8, IC9, IC10, IC11, IC13, IC14, IC15, IC16: DRV8874PWPR; SOP65P640X120-17N; Mouser Part Number 595-DRV8874PWPR
IC12: TCAN332DR; SOIC127P600X175-8N; Mouser Part Number 595-TCAN332DR
IC17: 74HC4067PW,118; SOP65P640X110-24N; Mouser Part Number 771-74HC4067PW-T
J1, J2, J3, J4, J5, J6, J7, J8, J12, J13, J14, J15: Conn_01x02_Pin; B2BXHAMLFSN; Mouser Part Number 306-B2B-XH-AMLFSNP
J9, J10, J17: Conn_01x02_Pin; SHDRRA2W50P0X200_1X2_600X770X525P; Mouser Part Number 306-B2B-XH-AMLFSNP
J11: 1729128; Mouser Part Number 651-1729128
J16: B4B-XH-A_LF__SN_; B4BXHALFSN; Mouser Part Number 306-B4BXHALFSN
L1: 10uH; SRP6060FA4R7M; Mouser Part Number 652-SRP6060FA-100M
L2: AOTA-B201610S3R3-101-T; AOTAB201610S3R3101T; Mouser Part Number 815-AB201610S3R3101T
R1: 510k; R_0603_1608Metric
R2, R4: 100k; R_0603_1608Metric; Mouser Part Number 303-0603WAF1003T5E
R3: 13K; R_0603_1608Metric
R5: 49.9; R_0603_1608Metric
R6: R33; R_0603_1608Metric
R7, R9, R11, R12, R15, R16, R19, R20, R25, R27, R29, R31, R34, R36: 10k; R_0603_1608Metric
R8, R10, R13, R14, R17, R18, R21, R22, R26, R28, R30, R32: 2,4k; R_0603_1608Metric; JLCPCB 0603WAF2401T5E
R23, R33, R35: R1K; R_0603_1608Metric
R24: R120; R_0603_1608Metric; not fitted
S1, S2: TS-1088-AR02016; TS1088AR02016; Manufacturer_Part_Number TS-1088-AR02016
TP1, TP2, TP3, TP7: TestPoint; TestPoint_Pad_D1.0mm_Silkless
TP4, TP5, TP6: TestPoint; TestPoint_Pad_D4.0mm_Silkless
Y1: ABM8-272-T3; ABM8272T3; Mouser Part Number 815-ABM8-272-T3

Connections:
3.3VIN: C1.1, C8.1, C12.1, C14.1, C15.1, C16.1, C17.1, C18.1, C19.1, C22.1, C23.1, C24.1, C25.1, C26.1, C37.1, C45.1, C48.1, C56.1, C60.1, C68.1, C73.1, C78.1, C98.1, D2.2 (A), IC1.5 (IOVDD_1), IC1.15 (IOVDD_2), IC1.24 (IOVDD_3), IC1.29 (IOVDD_4), IC1.41 (IOVDD_5), IC1.50 (IOVDD_6), IC1.59 (ADC_AVDD), IC1.60 (IOVDD_7), IC1.64 (VREG_VIN), IC1.68 (USB_OTP_VDD), IC1.69 (QSPI_IOVDD), IC1.76 (IOVDD_8), IC3.2 (OUTPUT_2), IC3.4 (OUTPUT), IC4.5 (VREF), IC5.5 (VREF), IC6.5 (VREF), IC7.5 (VREF), IC8.5 (VREF), IC9.5 (VREF), IC10.5 (VREF), IC11.5 (VREF), IC12.3 (VCC), IC13.5 (VREF), IC14.5 (VREF), IC15.5 (VREF), IC16.5 (VREF), IC17.24 (VCC), J16.2, R6.1, R7.2, R9.2, R11.2, R12.2, R15.2, R16.2, R19.2, R20.2, R25.2, R27.2, R29.2, R31.2, R34.2, R36.2, TP2.1 (1_1)
5VIN: C4.1, C5.1, C9.1, C10.1, D2.1 (K), IC3.3 (INPUT), J17.1, L1.2, R5.1, TP1.1 (1_1)
24VIN: C29.1, C30.1, C32.1, C33.2, C35.1, C36.1, C38.1, C39.2, C42.1, C43.1, C44.1, C46.1, C47.1, C49.1, C50.2, C51.2, C54.1, C55.1, C57.1, C58.1, C59.1, C61.1, C62.2, C63.2, C66.1, C67.1, C69.1, C70.1, C71.1, C72.1, C74.2, C75.2, C82.1, C83.1, C84.2, C85.2, C86.1, C87.1, C88.2, C89.2, C90.1, C91.1, C92.1, C93.1, C94.1, C95.1, C96.1, C97.1, C100.1, C101.1, C102.1, D1.1 (K), F1.1, FB1.1, IC4.11 (VM), IC5.11 (VM), IC6.11 (VM), IC7.11 (VM), IC8.11 (VM), IC9.11 (VM), IC10.11 (VM), IC11.11 (VM), IC13.11 (VM), IC14.11 (VM), IC15.11 (VM), IC16.11 (VM)
+1V1: C11.1, C20.1, C21.1, C27.1, IC1.10 (DVDD_1), IC1.32 (DVDD_2), IC1.51 (DVDD_3), IC1.65 (VREG_FB), L2.1, TP3.1 (1_1)
/ADC0: IC4.6 (IPROPI), IC17.22 (Y9), R8.1
/ADC1: IC6.6 (IPROPI), IC17.21 (Y10), R13.1
/ADC2: IC8.6 (IPROPI), IC17.20 (Y11), R17.1
/ADC3: IC10.6 (IPROPI), IC17.19 (Y12), R21.1
/ADC4: IC5.6 (IPROPI), IC17.18 (Y13), R10.1
/ADC5: IC7.6 (IPROPI), IC17.17 (Y14), R14.1
/ADC6: IC9.6 (IPROPI), IC17.8 (Y1), R18.1
/ADC7: IC11.6 (IPROPI), IC17.7 (Y2), R22.1
/ADC8: IC13.6 (IPROPI), IC17.4 (Y5), R26.1
/ADC9: IC14.6 (IPROPI), IC17.6 (Y3), R28.1
/ADC10: IC15.6 (IPROPI), IC17.5 (Y4), R30.1
/ADC11: IC16.6 (IPROPI), IC17.3 (Y6), R32.1
/Bouton test: C104.1, IC1.43 (GPIO34), R36.1, S2.1 (COM)
/FAULT0: IC1.48 (GPIO39), IC4.4 (NFAULT), R7.1
/FAULT1: IC1.46 (GPIO37), IC6.4 (NFAULT), R11.1
/FAULT2: IC1.1 (GPIO4), IC8.4 (NFAULT), R15.1
/FAULT3: IC1.80 (GPIO3), IC10.4 (NFAULT), R19.1
/FAULT4: IC1.11 (GPIO12), IC5.4 (NFAULT), R9.1
/FAULT5: IC1.8 (GPIO10), IC7.4 (NFAULT), R12.1
/FAULT6: IC1.17 (GPIO17), IC9.4 (NFAULT), R16.1
/FAULT7: IC1.16 (GPIO16), IC11.4 (NFAULT), R20.1
/FAULT8: IC1.26 (GPIO25), IC13.4 (NFAULT), R25.1
/FAULT9: IC1.22 (GPIO22), IC14.4 (NFAULT), R27.1
/FAULT10: IC1.39 (GPIO31), IC15.4 (NFAULT), R29.1
/FAULT11: IC1.36 (GPIO28), IC16.4 (NFAULT), R31.1
/FREQ OSC: IC1.52 (GPIO41_ADC1), TP7.1 (1_1)
/GND_TSP: IC2.1 (GND), R3.2
/MUX OUT: IC1.56 (GPIO45_ADC5), IC17.1 (Z)
/MUX_EN: IC1.53 (GPIO42_ADC2), IC17.15 (~E)
/PWM0: IC1.44 (GPIO35), IC4.1 (EN/IN1)
/PWM1: IC1.78 (GPIO1), IC6.1 (EN/IN1)
/PWM2: IC1.2 (GPIO5), IC8.1 (EN/IN1)
/PWM3: IC1.4 (GPIO7), IC10.1 (EN/IN1)
/PWM4: IC1.9 (GPIO11), IC5.1 (EN/IN1)
/PWM5: IC1.13 (GPIO14), IC7.1 (EN/IN1)
/PWM6: IC1.20 (GPIO20), IC9.1 (EN/IN1)
/PWM7: IC1.18 (GPIO18), IC11.1 (EN/IN1)
/PWM8: IC1.27 (GPIO26), IC13.1 (EN/IN1)
/PWM9: IC1.23 (GPIO23), IC14.1 (EN/IN1)
/PWM10: IC1.40 (GPIO32), IC15.1 (EN/IN1)
/PWM11: IC1.37 (GPIO29), IC16.1 (EN/IN1)
/RUN: C99.1, IC1.35 (RUN), R34.1, S1.1 (COM)
/RXD: IC1.57 (GPIO46_ADC6), IC12.4 (RXD)
/S0: IC1.55 (GPIO44_ADC4), IC17.10 (S0)
/S1: IC1.54 (GPIO43_ADC3), IC17.11 (S1)
/S2: IC1.47 (GPIO38), IC17.14 (S2)
/S3: IC1.45 (GPIO36), IC17.13 (S3)
/SDCLK: IC1.33 (SWCLK), J16.3
/SENS0: IC1.77 (GPIO0), IC4.2 (PH/IN2)
/SENS1: IC1.79 (GPIO2), IC6.2 (PH/IN2)
/SENS2: IC1.3 (GPIO6), IC8.2 (PH/IN2)
/SENS3: IC1.6 (GPIO8), IC10.2 (PH/IN2)
/SENS4: IC1.12 (GPIO13), IC5.2 (PH/IN2)
/SENS5: IC1.7 (GPIO9), IC7.2 (PH/IN2)
/SENS6: IC1.21 (GPIO21), IC9.2 (PH/IN2)
/SENS7: IC1.19 (GPIO19), IC11.2 (PH/IN2)
/SENS8: IC1.28 (GPIO27), IC13.2 (PH/IN2)
/SENS9: IC1.25 (GPIO24), IC14.2 (PH/IN2)
/SENS10: IC1.42 (GPIO33), IC15.2 (PH/IN2)
/SENS11: IC1.38 (GPIO30), IC16.2 (PH/IN2)
/SWDIO: IC1.34 (SWDIO), J16.4
/TXD: IC1.58 (GPIO47_ADC7), IC12.1 (TXD)
/VREG AVDD: C13.1, IC1.61 (VREG_AVDD), R6.2
/VREG LX: IC1.63 (VREG_LX), L2.2
/XIN: C76.1, IC1.30 (XIN), Y1.1 (CRYSTAL_1)
/XOUT: IC1.31 (XOUT), R23.1
/nSLEEP: IC1.14 (GPIO15), IC4.3 (NSLEEP), IC5.3 (NSLEEP), IC6.3 (NSLEEP), IC7.3 (NSLEEP), IC8.3 (NSLEEP), IC9.3 (NSLEEP), IC10.3 (NSLEEP), IC11.3 (NSLEEP), IC13.3 (NSLEEP), IC14.3 (NSLEEP), IC15.3 (NSLEEP), IC16.3 (NSLEEP)
CAN+: IC12.7 (CANH), J9.2, J10.1, R24.1
CAN-: IC12.6 (CANL), J9.1, J10.2, R24.2
GND: C1.2, C2.2, C4.2, C5.2, C7.2, C8.2, C9.2, C10.2, C11.2, C12.2, C13.2, C14.2, C15.2, C16.2, C17.2, C18.2, C19.2, C20.2, C21.2, C22.2, C23.2, C24.2, C25.2, C26.2, C27.2, C30.2, C32.2, C33.1, C36.2, C37.2, C38.2, C39.1, C43.2, C44.2, C45.2, C47.2, C48.2, C49.2, C50.1, C51.1, C55.2, C56.2, C57.2, C59.2, C60.2, C61.2, C62.1, C63.1, C67.2, C68.2, C69.2, C71.2, C72.2, C73.2, C74.1, C75.1, C76.2, C77.2, C78.2, C84.1, C85.1, C88.1, C89.1, C90.2, C91.2, C92.2, C93.2, C94.2, C95.2, C96.2, C97.2, C98.2, C99.2, C100.2, C101.2, C102.2, C103.2 (-), C104.2, D1.2 (A), IC1.62 (VREG_PGND), IC1.81 (GND), IC3.1 (ADJ/GND), IC4.7 (IMODE), IC4.9 (PGND), IC4.15 (GND), IC4.16 (PMODE), IC4.17 (EP), IC5.7 (IMODE), IC5.9 (PGND), IC5.15 (GND), IC5.16 (PMODE), IC5.17 (EP), IC6.7 (IMODE), IC6.9 (PGND), IC6.15 (GND), IC6.16 (PMODE), IC6.17 (EP), IC7.7 (IMODE), IC7.9 (PGND), IC7.15 (GND), IC7.16 (PMODE), IC7.17 (EP), IC8.7 (IMODE), IC8.9 (PGND), IC8.15 (GND), IC8.16 (PMODE), IC8.17 (EP), IC9.7 (IMODE), IC9.9 (PGND), IC9.15 (GND), IC9.16 (PMODE), IC9.17 (EP), IC10.7 (IMODE), IC10.9 (PGND), IC10.15 (GND), IC10.16 (PMODE), IC10.17 (EP), IC11.7 (IMODE), IC11.9 (PGND), IC11.15 (GND), IC11.16 (PMODE), IC11.17 (EP), IC12.2 (GND), IC13.7 (IMODE), IC13.9 (PGND), IC13.15 (GND), IC13.16 (PMODE), IC13.17 (EP), IC14.7 (IMODE), IC14.9 (PGND), IC14.15 (GND), IC14.16 (PMODE), IC14.17 (EP), IC15.7 (IMODE), IC15.9 (PGND), IC15.15 (GND), IC15.16 (PMODE), IC15.17 (EP), IC16.7 (IMODE), IC16.9 (PGND), IC16.15 (GND), IC16.16 (PMODE), IC16.17 (EP), IC17.12 (GND), J11.2, J16.1, J17.2, R2.1, R8.2, R10.2, R13.2, R14.2, R17.2, R18.2, R21.2, R22.2, R26.2, R28.2, R30.2, R32.2, R33.1, R35.1, TP4.1 (1_1), TP5.1 (1_1), TP6.1 (1_1), Y1.2 (GND_1), Y1.4 (GND_2)
unnamed: C6.2, R4.2, R5.2
unnamed: C2.1, C7.1, C103.1 (+), FB1.2, IC2.3 (VIN), R1.1
unnamed: F1.2, J11.1
unnamed: C3.2, IC2.6 (BOOT)
unnamed: IC2.5 (EN), R1.2, R2.2
unnamed: C6.1, IC2.4 (FB), R3.1, R4.1
unnamed: C3.1, IC2.2 (SW), L1.1
unnamed: C28.2, IC4.13 (CPH)
unnamed: C28.1, IC4.14 (CPL)
unnamed: IC4.8 (OUT1), J1.1
unnamed: IC4.10 (OUT2), J1.2
unnamed: C29.2, IC4.12 (VCP)
unnamed: C34.2, IC5.13 (CPH)
unnamed: C34.1, IC5.14 (CPL)
unnamed: IC5.8 (OUT1), J2.1
unnamed: IC5.10 (OUT2), J2.2
unnamed: C35.2, IC5.12 (VCP)
unnamed: C40.2, IC6.13 (CPH)
unnamed: C40.1, IC6.14 (CPL)
unnamed: IC6.8 (OUT1), J3.1
unnamed: IC6.10 (OUT2), J3.2
unnamed: C42.2, IC6.12 (VCP)
unnamed: C41.2, IC7.13 (CPH)
unnamed: C41.1, IC7.14 (CPL)
unnamed: IC7.8 (OUT1), J4.1
unnamed: IC7.10 (OUT2), J4.2
unnamed: C46.2, IC7.12 (VCP)
unnamed: C52.2, IC8.13 (CPH)
unnamed: C52.1, IC8.14 (CPL)
unnamed: IC8.8 (OUT1), J5.1
unnamed: IC8.10 (OUT2), J5.2
unnamed: C54.2, IC8.12 (VCP)
unnamed: C53.2, IC9.13 (CPH)
unnamed: C53.1, IC9.14 (CPL)
unnamed: IC9.8 (OUT1), J6.1
unnamed: IC9.10 (OUT2), J6.2
unnamed: C58.2, IC9.12 (VCP)
unnamed: C64.2, IC10.13 (CPH)
unnamed: C64.1, IC10.14 (CPL)
unnamed: IC10.8 (OUT1), J7.1
unnamed: IC10.10 (OUT2), J7.2
unnamed: C66.2, IC10.12 (VCP)
unnamed: C65.2, IC11.13 (CPH)
unnamed: C65.1, IC11.14 (CPL)
unnamed: IC11.8 (OUT1), J8.1
unnamed: IC11.10 (OUT2), J8.2
unnamed: C70.2, IC11.12 (VCP)
unnamed: C31.2, IC13.13 (CPH)
unnamed: C31.1, IC13.14 (CPL)
unnamed: IC13.8 (OUT1), J12.1
unnamed: IC13.10 (OUT2), J12.2
unnamed: C82.2, IC13.12 (VCP)
unnamed: C79.2, IC14.13 (CPH)
unnamed: C79.1, IC14.14 (CPL)
unnamed: IC14.8 (OUT1), J13.1
unnamed: IC14.10 (OUT2), J13.2
unnamed: C83.2, IC14.12 (VCP)
unnamed: C80.2, IC15.13 (CPH)
unnamed: C80.1, IC15.14 (CPL)
unnamed: IC15.8 (OUT1), J14.1
unnamed: IC15.10 (OUT2), J14.2
unnamed: C86.2, IC15.12 (VCP)
unnamed: C81.2, IC16.13 (CPH)
unnamed: C81.1, IC16.14 (CPL)
unnamed: IC16.8 (OUT1), J15.1
unnamed: IC16.10 (OUT2), J15.2
unnamed: C87.2, IC16.12 (VCP)
unnamed: R33.2, S1.2 (NO)
unnamed: R35.2, S2.2 (NO)
unnamed: C77.1, R23.2, Y1.3 (CRYSTAL_2)

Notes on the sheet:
FLASH
LDO
Crystal 12Mhz
CAN
13k au lieu de 13.3 pour utiliser une référence basic > 5,18V en sortie
MUX
Buck
Alim + protection + bulk
RP2548B
DRIVER
Tests points
Sortie alim pour la carte clavier

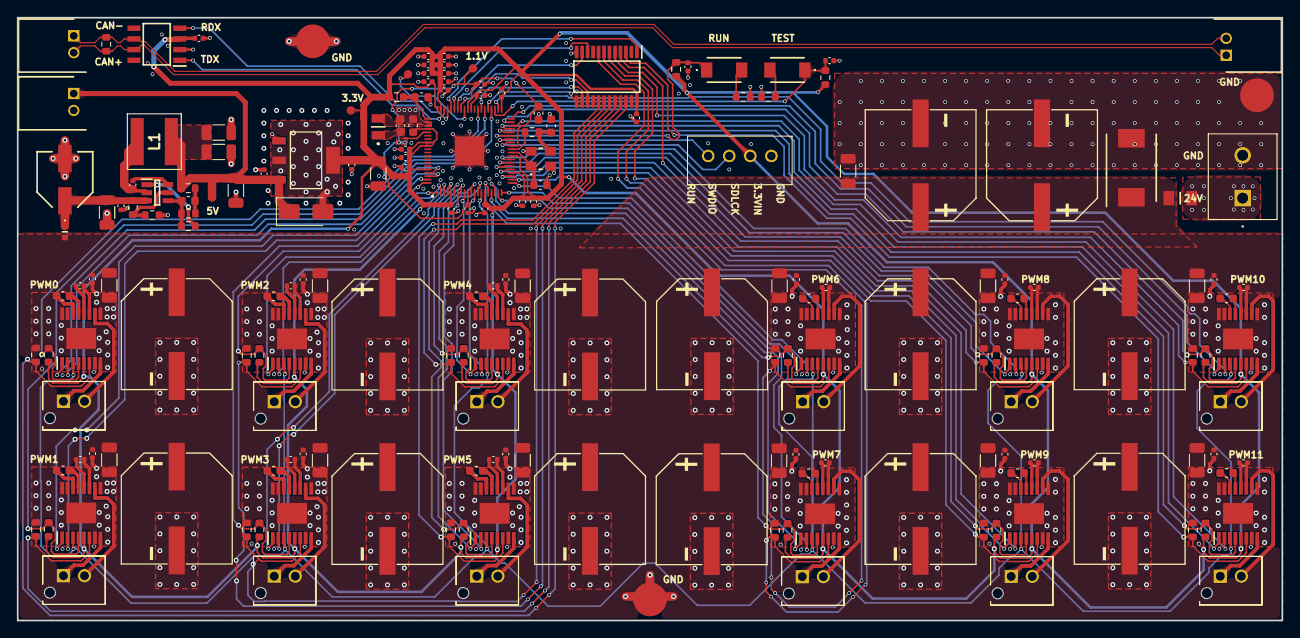
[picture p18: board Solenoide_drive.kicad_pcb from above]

Board: 4 copper layers, 150.0 x 71.5 mm, 190 parts (0 on the bottom side), 144 nets.

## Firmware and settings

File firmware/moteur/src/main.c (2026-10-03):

// Bring-up isolé canal 0 (Phase 2a de Docs/specs/Roadmap.md) : validation
// électrique basique (sens du courant, PWM), avant toute machine à états
// pull/hold/release et avant tout multi-canal ou CAN — hors périmètre ici.
#include <stdbool.h>
#include <stdint.h>

#include "hardware/gpio.h"
#include "hardware/pwm.h"
#include "pico/stdlib.h"

#include "config.h"

#define PWM_WRAP 9999u
#define PWM_DUTY_PERCENT 30u
#define TEST_BUTTON_DEBOUNCE_DELAY_MS 30u
#define MAIN_LOOP_POLL_DELAY_MS 5u

int main(void) {
    stdio_init_all();

    gpio_init(MOTEUR_GLOBAL_SLEEP_GPIO);
    gpio_set_dir(MOTEUR_GLOBAL_SLEEP_GPIO, GPIO_OUT);
    gpio_put(MOTEUR_GLOBAL_SLEEP_GPIO, true);  // nSLEEP actif haut : réveil du driver avant tout usage

    gpio_init(MOTEUR_DIR_CHANNEL0_GPIO);
    gpio_set_dir(MOTEUR_DIR_CHANNEL0_GPIO, GPIO_OUT);
    gpio_put(MOTEUR_DIR_CHANNEL0_GPIO, false);  // LOW = sens PULL, fixe pour ce test isolé

    gpio_init(MOTEUR_FAULT_CHANNEL0_GPIO);
    gpio_set_dir(MOTEUR_FAULT_CHANNEL0_GPIO, GPIO_IN);
    gpio_pull_up(MOTEUR_FAULT_CHANNEL0_GPIO);

    gpio_init(MOTEUR_TEST_BUTTON_GPIO);
    gpio_set_dir(MOTEUR_TEST_BUTTON_GPIO, GPIO_IN);
    gpio_pull_up(MOTEUR_TEST_BUTTON_GPIO);

    gpio_set_function(MOTEUR_PWM_CHANNEL0_GPIO, GPIO_FUNC_PWM);
    const uint pwm_slice = pwm_gpio_to_slice_num(MOTEUR_PWM_CHANNEL0_GPIO);
    const uint pwm_channel = pwm_gpio_to_channel(MOTEUR_PWM_CHANNEL0_GPIO);

    pwm_config config = pwm_get_default_config();
    pwm_config_set_wrap(&config, PWM_WRAP);
    pwm_init(pwm_slice, &config, false);
    pwm_set_chan_level(pwm_slice, pwm_channel, (PWM_WRAP * PWM_DUTY_PERCENT) / 100u);

    bool pwm_running = false;
    bool previous_button_level = true;  // pull-up : bouton relâché = niveau haut

    while (true) {
        // NFAULT actif bas : le driver signale un défaut, on coupe le PWM sans attendre
        // plutôt que de laisser le solénoïde activé hors de sa fenêtre de sécurité.
        if (!gpio_get(MOTEUR_FAULT_CHANNEL0_GPIO)) {
            pwm_set_enabled(pwm_slice, false);
            pwm_running = false;
        }

        const bool button_level = gpio_get(MOTEUR_TEST_BUTTON_GPIO);
        if (button_level != previous_button_level) {
            sleep_ms(TEST_BUTTON_DEBOUNCE_DELAY_MS);  // anti-rebond bloquant simple, suffisant pour ce test isolé
            const bool debounced_level = gpio_get(MOTEUR_TEST_BUTTON_GPIO);
            if (debounced_level != previous_button_level && !debounced_level) {
                // Front descendant confirmé (bouton actif bas) : bascule marche/arrêt du PWM.
                pwm_running = !pwm_running;
                pwm_set_enabled(pwm_slice, pwm_running);
            }
            previous_button_level = debounced_level;
        }

        sleep_ms(MAIN_LOOP_POLL_DELAY_MS);
    }
}

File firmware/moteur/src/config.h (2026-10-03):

// GPIO du canal 0 et des signaux partagés, recopiés depuis la table IMP-001 de
// Docs/adr/adr-0001-hal-solenoide-drv8874-phen.md (contrat HAL verrouillé).
// Ne PAS dériver ce fichier du pinmap généré (Netlist/netlist_to_pinmap.py) :
// les noms de net générés reprennent "SENS", explicitement rejeté par l'ADR-0001
// pour ne pas laisser croire à une mesure de courant par canal.
// Périmètre Phase 2a uniquement : un seul canal, pas de CAN, pas de machine à états.
#ifndef MOTEUR_CONFIG_H
#define MOTEUR_CONFIG_H

// Rôle logique : pin1 EN/IN1 du DRV8874, sortie PWM matérielle (hardware_pwm).
#define MOTEUR_PWM_CHANNEL0_GPIO 35u

// Rôle logique : pin2 PH/IN2 du DRV8874, sortie GPIO simple (direction).
#define MOTEUR_DIR_CHANNEL0_GPIO 0u

// Rôle logique : pin4 NFAULT du DRV8874, entrée GPIO actif bas.
#define MOTEUR_FAULT_CHANNEL0_GPIO 39u

// Rôle logique : pin3 NSLEEP, net partagé entre les 12 drivers.
#define MOTEUR_GLOBAL_SLEEP_GPIO 15u

// Bouton de test, actif bas.
#define MOTEUR_TEST_BUTTON_GPIO 34u

#endif  // MOTEUR_CONFIG_H

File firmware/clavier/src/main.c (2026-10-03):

#include <stdbool.h>
#include <stdint.h>
#include <stdio.h>

#include "pico/stdlib.h"

#include "keycode.h"
#include "keymap.h"
#include "matrix_scan.h"
#include "midi.h"
#include "note_state.h"

typedef struct {
    keycode_state_t keycode;
    note_state_t notes;
} clavier_state_t;

static void handle_matrix_transition(uint8_t position, bool pressed, void *context) {
    clavier_state_t *state = context;
    const keycode_t keycode = keymap_keycode_for_position(position);

    if (keycode.kind == KEYCODE_NONE) {
        printf("position %u unused %s\n", position, pressed ? "pressed" : "released");
        return;
    }

    if (keycode.kind == KEYCODE_NOTE) {
        uint8_t midi_note;

        if (pressed) {
            if (!note_state_press(&state->notes, &state->keycode, position,
                                  keycode.value, &midi_note)) {
                printf("position %u note resolution failed\n", position);
                return;
            }
            if (!midi_note_on(midi_note, MIDI_NOTE_VELOCITY)) {
                printf("position %u note %u pressed, USB MIDI unavailable\n",
                       position, midi_note);
            }
        } else if (note_state_release(&state->notes, position, &midi_note)) {
            if (!midi_note_off(midi_note)) {
                printf("position %u note %u released, USB MIDI unavailable\n",
                       position, midi_note);
            }
        }
        return;
    }

    if (pressed) {
        keycode_press(&state->keycode, keycode);
    }
    if (keycode.kind == KEYCODE_ALTERATION) {
        printf("position %u behavior %s state %u %s\n", position, keycode_name(keycode),
               keycode_alteration_state(&state->keycode, keycode),
               pressed ? "pressed" : "released");
        return;
    }
    printf("position %u behavior %s %s\n", position, keycode_name(keycode),
           pressed ? "pressed" : "released");
}

int main(void) {
    clavier_state_t state;

    stdio_init_all();
    matrix_scan_init();
    keycode_state_init(&state.keycode);
    note_state_init(&state.notes);
    midi_init();

    while (true) {
        midi_task();
        matrix_scan_poll(handle_matrix_transition, &state);
        sleep_us(215);
    }
}

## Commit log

2026-08-30 mises à jour photo readme2
    [Clavier_drive_1.kicad_pcb, Clavier_drive_1.kicad_sch, Solenoide_drive.kicad_pcb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]
2026-10-03 ajout firmware + modif readme
    [BOM-Clavier_drive_1.csv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]
2026-10-03 ajout firmware + modif readme2
    [BOM-Clavier_drive_1.csv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]
2026-10-03 ajout firmware + modif readme3
    [Clavier_drive_1.kicad_pcb, Clavier_drive_1.kicad_sch, Solenoide_drive.kicad_pcb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]
2026-10-07 ajout proto bobine
    [coil_configs.xlsx]
